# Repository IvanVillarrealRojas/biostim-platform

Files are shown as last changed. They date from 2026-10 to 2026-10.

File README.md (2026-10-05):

# Biostim-platform
 
**Low-cost, open-source bioelectronic platform for electrical stimulation and real-time environmental monitoring of cell-laden hydrogels.**
 
A compact, modular system that applies controlled electrical stimulation to a cell-culture hydrogel while continuously monitoring the variables that matter for cell viability: temperature, pH, and the electric field distributed across the sample. It is built entirely from low-cost, widely available components and a single Raspberry Pi Pico 2 W, and it exposes all of its data through a self-hosted web dashboard reachable from any browser on the same network.
 
The goal of the project is to make in-vitro electrostimulation accessible to laboratories, universities and schools that cannot justify the cost of commercial systems, which are typically closed, expensive, and difficult to adapt to a specific experiment.
 
---
 
## Why this project exists
 
Electrical signalling governs a wide range of biological processes, and electrostimulation of cell cultures is an increasingly common technique for studying how different cell types respond to electric fields. The commercial equipment that enables this is usually priced in the thousands of euros, built on closed architectures, and offers little room for customisation or real-time data access.
 
This platform is a response to that gap. It integrates, in a single and reusable device that costs roughly €110 in materials per unit, functions that are normally split across several independent instruments: programmable stimulation, distributed field measurement inside the hydrogel, continuous environmental monitoring, and a real-time control interface.
 
---
 
## Features
 
- **Analog acquisition chain** — Three platinum sensing electrodes distributed along the channel, read through two CD74HC4067 multiplexers, an INA333 instrumentation amplifier centred on a 1.65 V reference, and a 24-bit ADS1220 ADC over SPI. Any differential pair of electrodes can be selected by software to measure the potential difference and compute the local electric field (E = ΔV/d).
- **Stimulation monitoring** — An INA226 sensor measures the real voltage and current delivered to the electrodes, allowing the system to detect effects such as electrode polarisation, where the effective voltage at the electrode drops over time even while the source holds constant.
- **Environmental monitoring** — Two DS18B20 digital temperature sensors on a shared 1-Wire bus (one internal to the channel, one ambient reference) and a glass-electrode pH probe through a conditioning module.
- **Self-hosted web dashboard** — A single-page interface served directly by the Pico over Wi-Fi. Live status cards, historical charts for temperature, pH and electric field, a configurable optimal-zone threshold system, and optional auto-stop safety limits.
- **Optional closed-loop control** — A host-side Python script (`control_GPD.py`) that reads the real electrode voltage from the dashboard and automatically adjusts a GW Instek GPD-series bench power supply over serial to hold a target voltage, compensating for electrode polarisation, with a current safety cut-off.
- **Fully modular firmware** — Written in MicroPython, one module per subsystem, so each stage can be understood, tested and replaced independently.
---
 
## Hardware architecture
 
The Raspberry Pi Pico 2 W coordinates every stage of the system. The complete pin map is as follows.
 
| GPIO | Protocol | Connection |
|---|---|---|
| GP2 | Digital | DRV8833 IN1 |
| GP3 | Digital | DRV8833 IN2 (unipolar configuration) |
| GP4 | I2C SDA | INA226 |
| GP5 | I2C SCL | INA226 |
| GP6, GP7, GP8 | Digital | MUX A select lines S0, S1, S2 |
| GP9, GP10, GP11 | Digital | MUX B select lines S0, S1, S2 |
| GP12 | Digital | ADS1220 DRDY |
| GP16 | SPI MISO | ADS1220 |
| GP17 | SPI CS | ADS1220 |
| GP18 | SPI SCLK | ADS1220 |
| GP19 | SPI MOSI | ADS1220 |
| GP21 | 1-Wire | DS18B20 internal + DS18B20 ambient (shared bus) |
| GP26 | ADC | pH module output (Po) |
 
The acquisition stage is protected against the higher-voltage stimulation stage by a cascade of series resistors, BAT54 clamp diodes, bias resistors to the 1.65 V reference, and input/output RC filtering. The physical platform is a 3D-printed resin chamber with a confined millimetric channel and an interchangeable glass-slide base for microscope compatibility.

The complete electronic schematic, including the full protection cascade, is available in hardware/ as a viewable PDF. An editable EasyEDA source (schematic.epro2) is also provided. The password to open it can be requested by email at ivi.280504@gmail.com.

The 3D-printable models for the chamber and the removable spacers are in 3d-models/, provided as STL files ready for slicing and as OBJ/MTL for viewing and editing. They were printed in Clear V4 resin on a Formlabs SLA printer.
 
### Stimulation and INA226 wiring
 
The stimulation voltage is supplied by an external regulated power supply connected to the electrodes through the INA226. Bench testing was carried out with a GW Instek GPD-2303 programmable supply, which is also the unit the optional `control_GDP.py` script drives over serial. The module used here exposes separate **V−**, **Current (+/−)** and **V+** screw terminals; the connection that correctly reports both the electrode voltage and the injected current is
 
```
V+        -> positive electrode        (measures the real voltage at the electrode)
V-        -> common GND
Current+  -> power-supply positive
Current-  -> positive electrode
Negative electrode -> common GND
Power-supply GND   -> common GND
```
 
With this wiring the bus-voltage reading reflects the voltage actually present at the electrode relative to ground, and the current is measured through the module's internal shunt (R002 = 0.002 Ω).

The system does not require a bench supply. It can equally be driven from batteries by inserting an H-bridge such as the DRV8833 between the battery and the electrodes, provided the battery voltage stays within the limits of the H-bridge and the rest of the system's protection stages. Driving the H-bridge from the Pico's PWM then allows lower or variable effective voltages to be produced by adjusting frequency and duty cycle. Operation has been verified in this configuration with a standard 9 V battery.
 
---
 
## Repository structure
 
```
biostim-platform/
├── firmware/            MicroPython code that runs on the Raspberry Pi Pico 2 W
│   ├── main.py          Entry point: initialises all modules, serves the dashboard
│   ├── wifi.py          Wi-Fi connection helper
│   ├── temp_sensor.py   DS18B20 driver (shared 1-Wire bus, selection by ROM index)
│   ├── ph_sensor.py     pH reading and voltage-to-pH mapping
│   ├── ads1220.py       ADS1220 24-bit ADC driver (SPI)
│   ├── mux.py           CD74HC4067 dual-multiplexer controller
│   └── stimulation.py   INA226 voltage/current/power monitor (I2C)
├── dashboard/
│   └── dashboard.html   Self-contained web interface (HTML/CSS/JS)
├── pc/
│   └── control_GPD.py   Optional closed-loop voltage control (runs on a PC)
├── hardware/
│   └── schematic.pdf    Complete electronic schematic (viewable)
│   └── schematic.epro2  Editable source (EasyEDA; password on request)
├── 3d-models/
│   ├── platform/        Main microfluidic chamber (STL + OBJ/MTL)
│   └── spacers/         Removable channel spacers (STL + OBJ/MTL)
├── README.md
└── LICENSE
```
 
---
 
## Getting started
 
### 1. Flash MicroPython
 
Install the latest MicroPython firmware for the Raspberry Pi Pico 2 W following the official Raspberry Pi instructions.
 
### 2. Upload the firmware
 
Copy every file from `firmware/` and the `dashboard/dashboard.html` file to the root of the Pico, using Thonny or the MicroPico extension for VS Code. The dashboard must sit next to `main.py` because the Pico serves it as a static file.
 
### 3. Set your Wi-Fi credentials
 
Edit the `SSID` and `PASSWORD` fields at the top of `main.py`.
 
### 4. Run
 
Execute `main.py`. The console prints the IP address assigned to the Pico. Open that address in any browser on the same network to reach the dashboard.
 
### 5. (Optional) Closed-loop control
 
To hold a constant voltage at the electrode and compensate for polarisation, connect a GW Instek GPD-series supply over serial, edit the `PICO_URL`, `COM_PORT` and target parameters at the top of `pc/control_GPD.py`, and run it on your computer. It logs the session to CSV and includes a current safety cut-off.
 
---
 
## Current status
 
The platform is functional and has been validated on the bench: Wi-Fi connectivity, the full sensor suite, the acquisition chain, and the INA226 voltage and current measurements all work, and the dashboard updates in real time. The system is suitable for use in experiments today, and remains under active development toward a fully polished release.
 
### Planned work
 
- Integration of the circuit onto a dedicated PCB to replace the breadboard wiring and enable an enclosure.
- Permanent, repeatable electrode connectors on the platform surface.
- Extension to bipolar stimulation with appropriate filtering.
- Remote dashboard access beyond the local network (cloud/IoT or a USB desktop application).
- Geometric optimisation of the chamber with smaller, specialised sensors for flexible experiment configurations.
- Validation with live cell cultures.
  
---
 
## Credits and attribution
 
This platform — its original concept, hardware architecture, firmware and dashboard — was designed and developed by **Iván Villarreal Rojas** and **Ximena Natalia L Gamiz Salas** (2026).
 
If you use, build upon, fork or continue this project, in whole or in part, please credit the original work:
 
> Based on the biostim-platform originally designed and developed by Iván Villarreal Rojas and Ximena Natalia L Gamiz Salas (2026).
 
Academic or derivative work that extends this platform should cite the original author accordingly.
 
---
 
## License
 
Released under the MIT License. See [LICENSE](LICENSE) for details. You are free to use, modify and distribute this work, including commercially, provided the original copyright and attribution are retained.

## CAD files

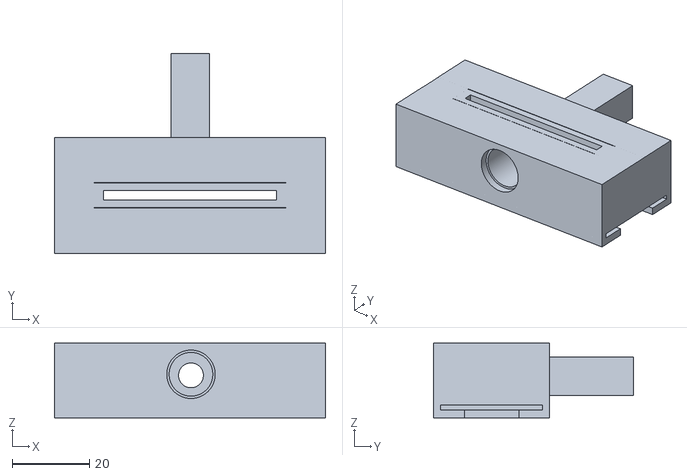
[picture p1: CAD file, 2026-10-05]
3d-models/platform/platform.stl
70.0 x 51.6 x 19.3

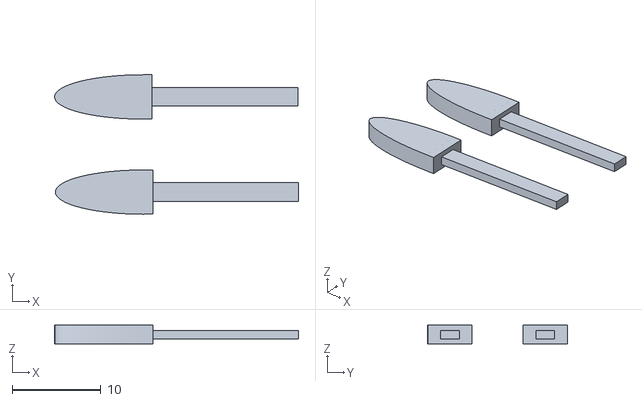
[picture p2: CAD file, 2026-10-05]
3d-models/spacers/spacers.stl
27.5 x 15.7 x 2.11

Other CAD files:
3d-models/spacers/tinker.obj
3d-models/platform/tinker.obj

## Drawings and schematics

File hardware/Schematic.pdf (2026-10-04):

# AVDD 10 REFP0 11 REFN0 12 AIN3 13 AIN2 14 AIN1 15 AIN0 16

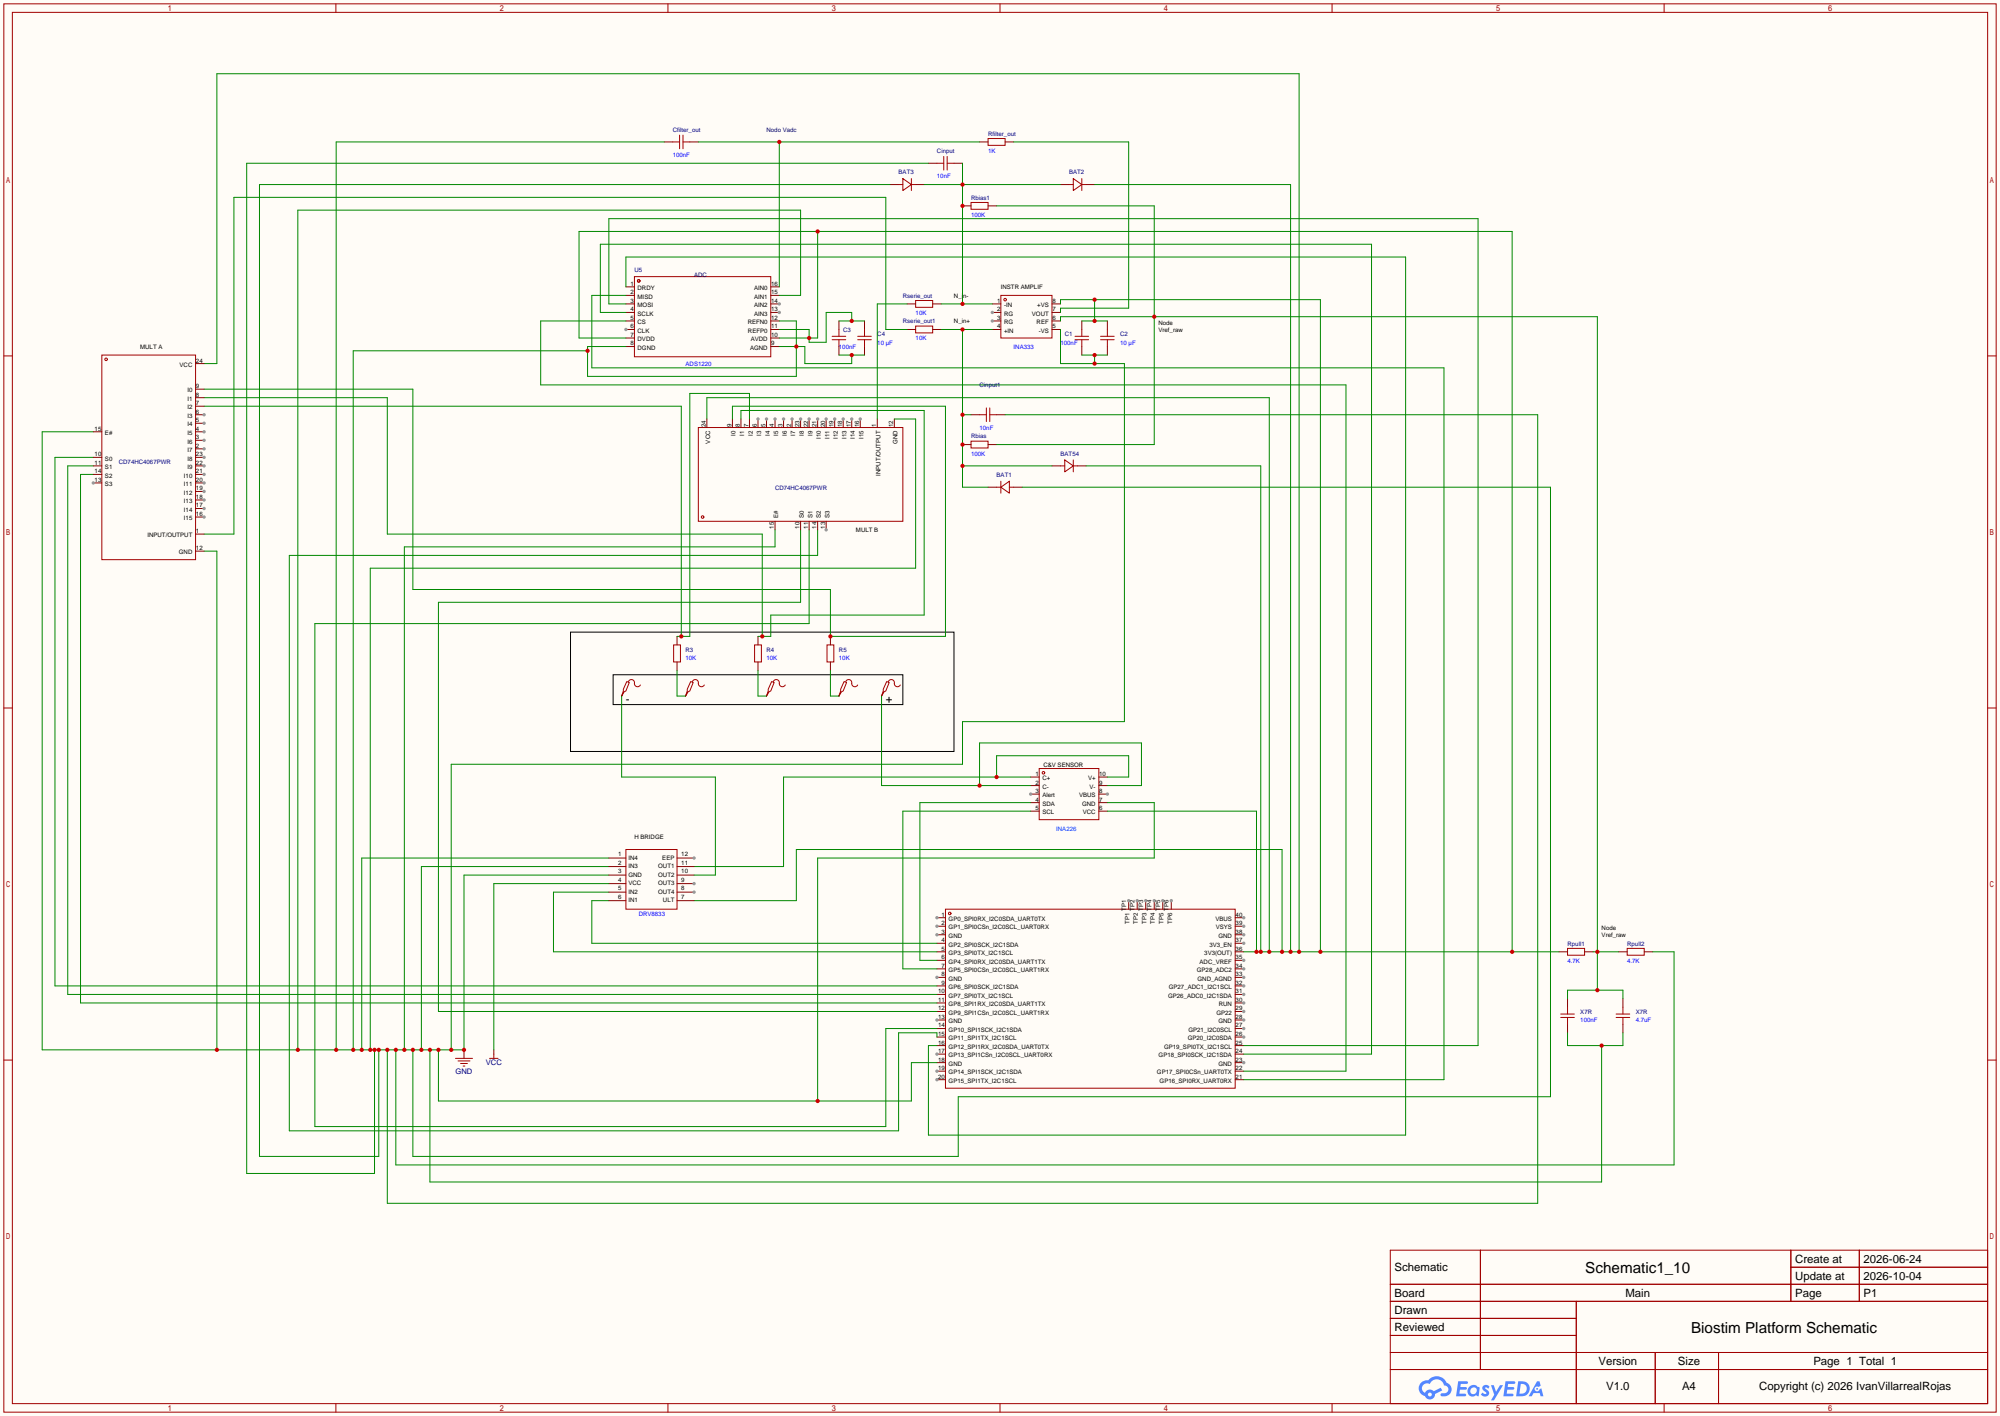
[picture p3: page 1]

Cinput

Node Vref_raw

Cinput1

IN3 2
GND 3

Schematic | Schematic1_10 | Create at | 2026-06-24

Update at | 2026-10-04

Board | Main | Page | P1
Drawn | | Biostim Platform Schematic
Reviewed

Version | Size | Page 1 Total 1
V1.0 | A4 | Copyright (c) 2026 IvanVillarrealRojas

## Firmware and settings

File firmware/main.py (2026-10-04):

"""
main.py  —  Plataforma bioelectrónica de bajo coste
Fuente regulable externa conectada directamente a electrodos via INA226.
Sin DRV8833. La estimulación se controla manualmente desde la fuente.
"""

from wifi import connect_wifi
from temp_sensor import TempSensor
from ph_sensor import get_ph
from ads1220 import ADS1220
from mux import DualMUX
from stimulation import INA226

import network, socket
from machine import I2C, Pin

# ── Credenciales WiFi ─────────────────────────────────────────────────────────
SSID     = "YOUR_SSID"
PASSWORD = "YOUR_PASSWORD"

# ── Distancias entre electrodos (mm) ─────────────────────────────────────────
DISTANCES = {"E1-E2": 20.0, "E1-E3": 40.0, "E2-E3": 20.0}

# ── Inicialización ────────────────────────────────────────────────────────────
connect_wifi(SSID, PASSWORD)
ip = network.WLAN(network.STA_IF).ifconfig()[0]
print("IP:", ip)

sensor_interno  = TempSensor(pin_num=21, rom_index=0)
sensor_ambiente = TempSensor(pin_num=21, rom_index=1)
adc   = ADS1220()
muxs  = DualMUX()
i2c   = I2C(0, sda=Pin(4), scl=Pin(5), freq=100_000)
monitor = INA226(i2c)


# ── Lectura de todos los sensores ─────────────────────────────────────────────
def read_all():
    ti        = sensor_interno.read_temp_c()
    te        = sensor_ambiente.read_temp_c()
    ph, volt  = get_ph()
    pairs     = muxs.scan_all_pairs(adc)
    sv        = monitor.read_bus_voltage()
    sc        = monitor.read_current()
    sp        = monitor.read_power()
    return ti, te, ph, volt, pairs, sv, sc, sp


def build_json(ti, te, ph, volt, pairs, sv, sc, sp):
    def fv(v): return "{:.4f}".format(v) if v is not None else "null"
    return (
        '{{"temp_int":{ti},"temp_ext":{te},"ph":{ph},"ph_volt":{pv},'
        '"diff_E1E2":{d12},"diff_E1E3":{d13},"diff_E2E3":{d23},'
        '"stim_voltage":{sv},"stim_current":{sc},"stim_power":{sp}}}'
    ).format(
        ti=fv(ti), te=fv(te), ph=fv(ph), pv=fv(volt),
        d12=fv(pairs.get("E1-E2")), d13=fv(pairs.get("E1-E3")), d23=fv(pairs.get("E2-E3")),
        sv=fv(sv), sc=fv(sc), sp=fv(sp)
    )


# ── Utilidades HTTP ───────────────────────────────────────────────────────────
def send_file(cl, path, mime):
    try:
        cl.send("HTTP/1.1 200 OK\r\nContent-Type: {}\r\n\r\n".format(mime))
        with open(path, "rb") as f:
            while True:
                chunk = f.read(512)
                if not chunk: break
                cl.sendall(chunk)
    except OSError:
        pass


def parse_param(req, key):
    try:
        idx = req.index(key + "=") + len(key) + 1
        end = req.find("&", idx)
        return req[idx:] if end == -1 else req[idx:end]
    except ValueError:
        return None


# ── Servidor web ──────────────────────────────────────────────────────────────
addr = socket.getaddrinfo("0.0.0.0", 80)[0][-1]
s = socket.socket()
s.setsockopt(socket.SOL_SOCKET, socket.SO_REUSEADDR, 1)
s.bind(addr)
s.listen(1)
print("Dashboard: http://{}".format(ip))


# ── Bucle principal ───────────────────────────────────────────────────────────
while True:
    try:
        cl, addr = s.accept()
        req = cl.recv(1024).decode("utf-8", "ignore")

        if "GET /data" in req:
            ti, te, ph, volt, pairs, sv, sc, sp = read_all()
            body = build_json(ti, te, ph, volt, pairs, sv, sc, sp)
            cl.send("HTTP/1.1 200 OK\r\nContent-Type: application/json\r\n\r\n")
            cl.sendall(body)

        else:
            send_file(cl, "dashboard.html", "text/html")

        cl.close()

    except OSError:
        try: cl.close()
        except: pass

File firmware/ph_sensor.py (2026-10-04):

# ph_sensor.py
#
# Lectura y conversión de tensión a pH para un módulo de pH
# conectado a GP26 (ADC0) de la Raspberry Pi Pico.
#
# Suposiciones:
#   - El ADC NUNCA recibe más de 3.3 V (ya sea directo o con divisor).
#   - Se hace un mapeo lineal:
#         0.0 V  -> pH 14
#         1.65 V -> pH 7
#         3.3 V  -> pH 0
#
#   - Esta relación es aproximada. Para tener medida real,
#     más adelante puedes sustituir la fórmula por una calibrada
#     con buffers pH 4 y pH 7.

from machine import ADC, Pin

# ADC en GP26
adc_ph = ADC(Pin(26))

VREF = 3.3              # máximo que verá el ADC
ADC_MAX = 65535         # read_u16() devuelve 0..65535

PH_MIN = 0.0            # pH mínimo del rango
PH_MAX = 14.0           # pH máximo del rango

def get_ph():
    """
    Lee el ADC en GP26, calcula el voltaje (0..3.3 V)
    y lo mapea linealmente a un pH entre 0 y 14.

    Devuelve:
        (ph, volt)
    """
    raw = adc_ph.read_u16()
    volt = (raw / ADC_MAX) * VREF

    # Mapeo lineal:
    #   volt = 0   -> pH = PH_MAX
    #   volt = VREF -> pH = PH_MIN
    #
    #   pH = PH_MAX - (volt / VREF) * (PH_MAX - PH_MIN)
    ph = PH_MAX - (volt / VREF) * (PH_MAX - PH_MIN)

    # Opcional: limitar por si hay pequeñas desviaciones numéricas
    if ph < PH_MIN:
        ph = PH_MIN
    if ph > PH_MAX:
        ph = PH_MAX

    return ph, volt


# Pequeño test si ejecutas este archivo directamente
if __name__ == "__main__":
    import time
    while True:
        ph, volt = get_ph()
        print("Voltaje:", round(volt, 3), "V   pH:", round(ph, 2))
        time.sleep(1)

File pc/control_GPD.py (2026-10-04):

import serial, requests, time, csv

# ── Configuración ─────────────────────────────────────────────
PICO_URL     = "PICO_URL"   # IP de tu Pico ------------- CHANGE
COM_PORT     = "COM_PORT"                          # ------------- CHANGE
BAUD         = 9600

V_TARGET     = 9.0     # V objetivo en el electrodo (lectura INA226) ------------- CHANGE
V_SOURCE_MAX = 15.0    # techo de seguridad para la fuente ------------- CHANGE
V_SOURCE_MIN = 0.0
I_SAFETY     = 0.050   # 50 mA límite de corriente — parada de emergencia   ------------- CHANGE
KP           = 0.5     # ganancia proporcional, empezar bajo  ------------- CHANGE

PERIOD_S     = 1.0     # frecuencia del bucle

# ── Inicialización ────────────────────────────────────────────
psu = serial.Serial(COM_PORT, BAUD, timeout=1)

def send(cmd):
    psu.write((cmd + "\n").encode())
    time.sleep(0.02)   # respetar los 10 ms mínimos

v_source = V_TARGET
send(f"ISET1:{I_SAFETY:.3f}")
send(f"VSET1:{v_source:.3f}")
send("OUT1")

# ── Log CSV ───────────────────────────────────────────────────
log = open("test_bucle.csv", "w", newline="")
writer = csv.writer(log)
writer.writerow(["t_s", "v_elec", "i_elec_mA", "v_source_cmd", "evento"])
t0 = time.time()

# ── Bucle de control ──────────────────────────────────────────
try:
    while True:
        try:
            r = requests.get(PICO_URL, timeout=5).json()
            v_elec = float(r["stim_voltage"])
            i_elec = float(r["stim_current"])
        except Exception as e:
            print("Error leyendo Pico:", e)
            time.sleep(PERIOD_S)
            continue

        # ── Chequeo de seguridad ANTES de tocar la fuente ──────
        if i_elec > I_SAFETY:
            send("OUT0")
            print(f"⚠ Parada de emergencia por sobrecorriente: "
                  f"i_elec={i_elec*1000:.1f} mA > {I_SAFETY*1000:.1f} mA")
            writer.writerow([f"{time.time()-t0:.1f}", f"{v_elec:.3f}",
                              f"{i_elec*1000:.2f}", f"{v_source:.3f}",
                              "PARADA_EMERGENCIA"])
            log.flush()
            break

        error    = V_TARGET - v_elec
        v_source = max(V_SOURCE_MIN, min(V_SOURCE_MAX, v_source + KP * error))
        send(f"VSET1:{v_source:.3f}")

        print(f"V_elec={v_elec:.3f} V  I_elec={i_elec*1000:.1f} mA  "
              f"→ VSET={v_source:.3f} V")

        writer.writerow([f"{time.time()-t0:.1f}", f"{v_elec:.3f}",
                          f"{i_elec*1000:.2f}", f"{v_source:.3f}", ""])
        log.flush()

        time.sleep(PERIOD_S)

except KeyboardInterrupt:
    send("OUT0")
    print("Parada segura por el usuario.")

finally:
    log.close()
    psu.close()

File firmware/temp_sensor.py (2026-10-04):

# temp_sensor.py
#
# Clase para leer sensores DS18B20 mediante el protocolo 1-Wire.
# Permite tener dos sensores (interno y ambiente) en el mismo pin GP21,
# seleccionándolos por su índice en el bus.
#
# Conexión: ambos DS18B20 → GP21, resistencia pull-up de 4.7 kΩ a 3.3 V.

import machine
import onewire
import ds18x20
import time


class TempSensor:
    def __init__(self, pin_num, rom_index=0):
        """
        pin_num:   número de GPIO al que está conectado el bus 1-Wire.
        rom_index: índice del sensor en el bus (0 = primero encontrado,
                   1 = segundo encontrado). Permite distinguir interno
                   de ambiente cuando comparten el mismo pin.
        """
        self.pin       = machine.Pin(pin_num)
        self.ow        = onewire.OneWire(self.pin)
        self.ds        = ds18x20.DS18X20(self.ow)
        self.rom_index = rom_index

        self.roms = self.ds.scan()
        print(f"[TempSensor] GP{pin_num} → {len(self.roms)} dispositivo(s) encontrado(s)")

        if not self.roms:
            raise RuntimeError(
                f"No se encontró ningún DS18B20 en GP{pin_num}. "
                "Revisa el cableado y la resistencia pull-up de 4.7 kΩ."
            )
        if rom_index >= len(self.roms):
            raise RuntimeError(
                f"Se pidió el sensor con índice {rom_index} "
                f"pero solo hay {len(self.roms)} sensor(es) en GP{pin_num}."
            )

    def read_temp_c(self):
        """Devuelve la temperatura en °C del sensor seleccionado por rom_index."""
        self.ds.convert_temp()
        time.sleep_ms(750)          # Tiempo de conversión del DS18B20 (máx. 750 ms)
        return self.ds.read_temp(self.roms[self.rom_index])

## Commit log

2026-10-04 Schematic upload
2026-10-05 Adding 3d-models
    [platform.stl, spacers.stl, tinker.obj]
